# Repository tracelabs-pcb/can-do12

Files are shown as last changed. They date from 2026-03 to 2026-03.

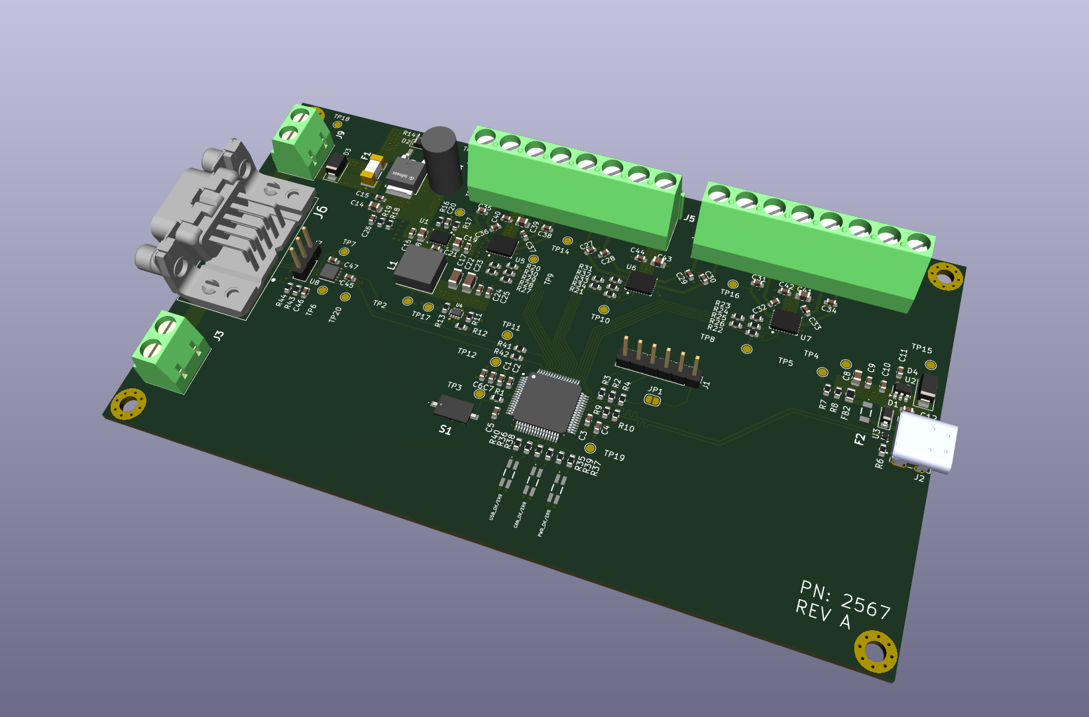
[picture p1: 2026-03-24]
screenshots/pcb_3d.png

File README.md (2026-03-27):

# CAN-DO12 — 24V Aktor-Modul (12x High-Side Digital Outputs)

**Status: PCB-Design abgeschlossen — unbestückt**  
**Tool:** KiCad | **Layer:** 4-Layer | **Hersteller-ready:** Ja

---

## Projektbeschreibung

Kompaktes 24V-Aktormodul zur Ansteuerung von 12 digitalen Lasten 
im Labor- und Prüfstandsbetrieb. Ansteuerung über CAN 2.0B, 
zusätzlich USB-C Service-Port für Parametrierung und Diagnose.
Entwickelt als Prototyp für Prüfstands- und Sondermaschinenbau.

**Besonderheiten:**
- 12x High-Side Ausgänge (24V / 1A je Kanal)
- CAN 2.0B (1 Mbit/s) + USB-C Full-Speed Device
- TVS + Verpolschutz am 24V Eingang
- ESD-Schutz an CAN und USB
- 4-Layer Layout, 140×80mm, Hutschienen-tauglich

---

## Hardware

| Komponente | Beschreibung |
|---|---|
| MCU | USB FS + CAN (STM32-Familie) |
| Ausgangstreiber | 12x High-Side, 24V |
| Schnittstellen | CAN 2.0B, USB-C, SWD |
| Versorgung | 18…30V DC, Buck → 3.3V |
| Schutz | TVS, Verpolschutz, ESD |
| Stackup | 4-Layer (Signal / GND / PWR / Signal) |
| Tool | KiCad |

---

## Anschlüsse

- USB-C (kurze Kante, mittig)
- DE-9 CAN-Stecker
- 2-pol Schraubklemme 24V Eingang
- 2x 8-pol Schraubklemme Ausgänge
- SWD Header (2.54mm)
- Jumper CAN-Terminierung 120Ω

---

## Ausschlüsse

Kein Serienprodukt — kein CE/EMV, keine Safety-Anwendung,
keine galvanische Trennung, keine Firmware.

---

## Dateien in diesem Repository

- `/kicad/` — KiCad Projektdateien
- `/screenshots/` — PCB- und Schematic-Ansichten

---

> Entwickelt von [Shawn Schneider](https://tracelabs-pcb.de)  
> — PCB-Design & Lötservice, Wolfsburg

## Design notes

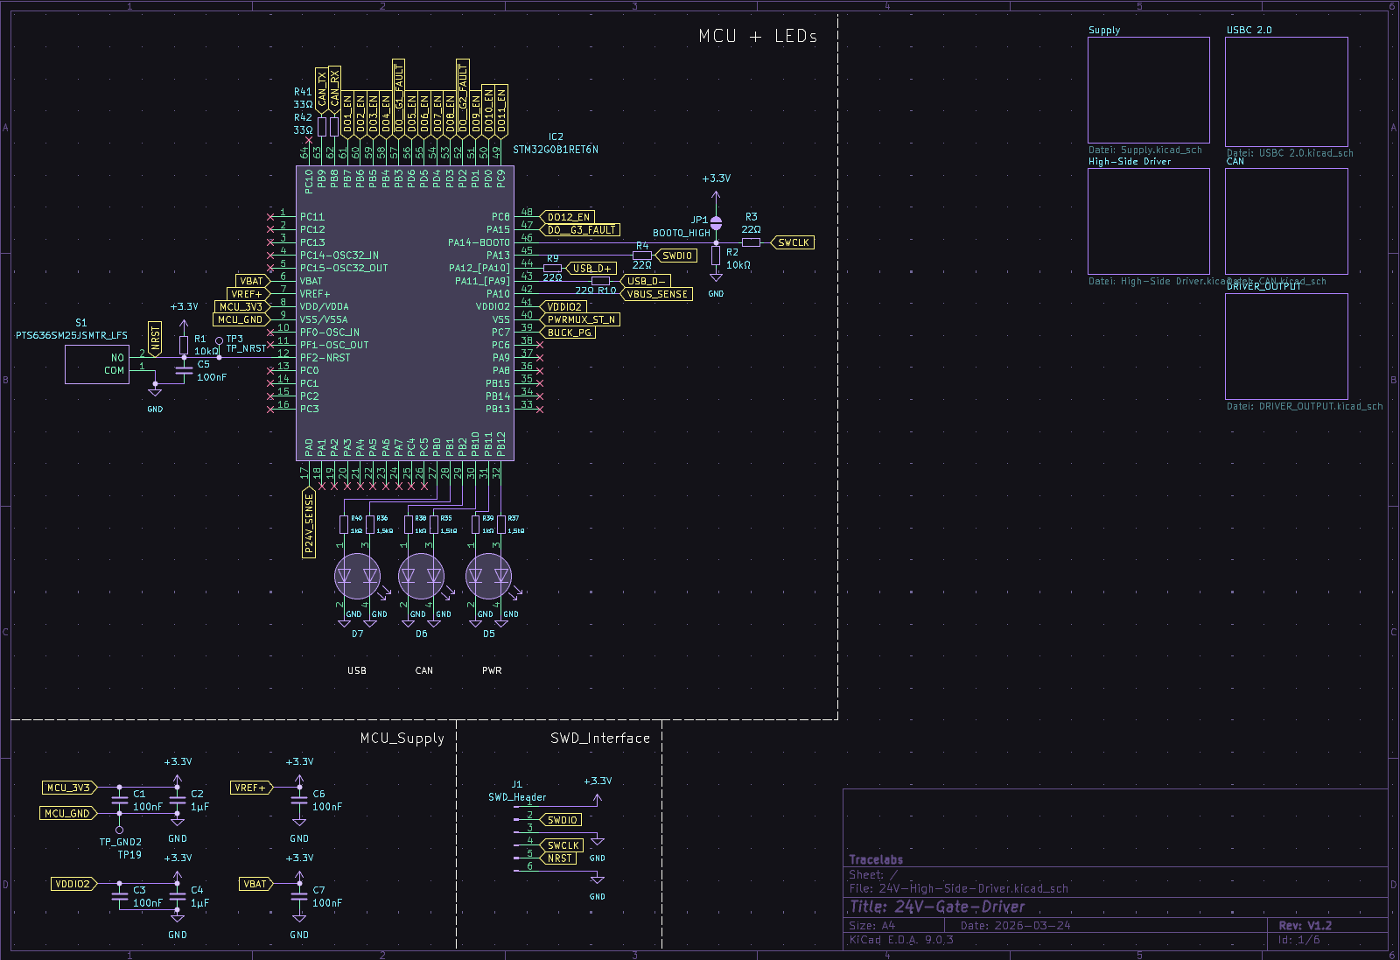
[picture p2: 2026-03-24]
screenshots/schematic_main.png

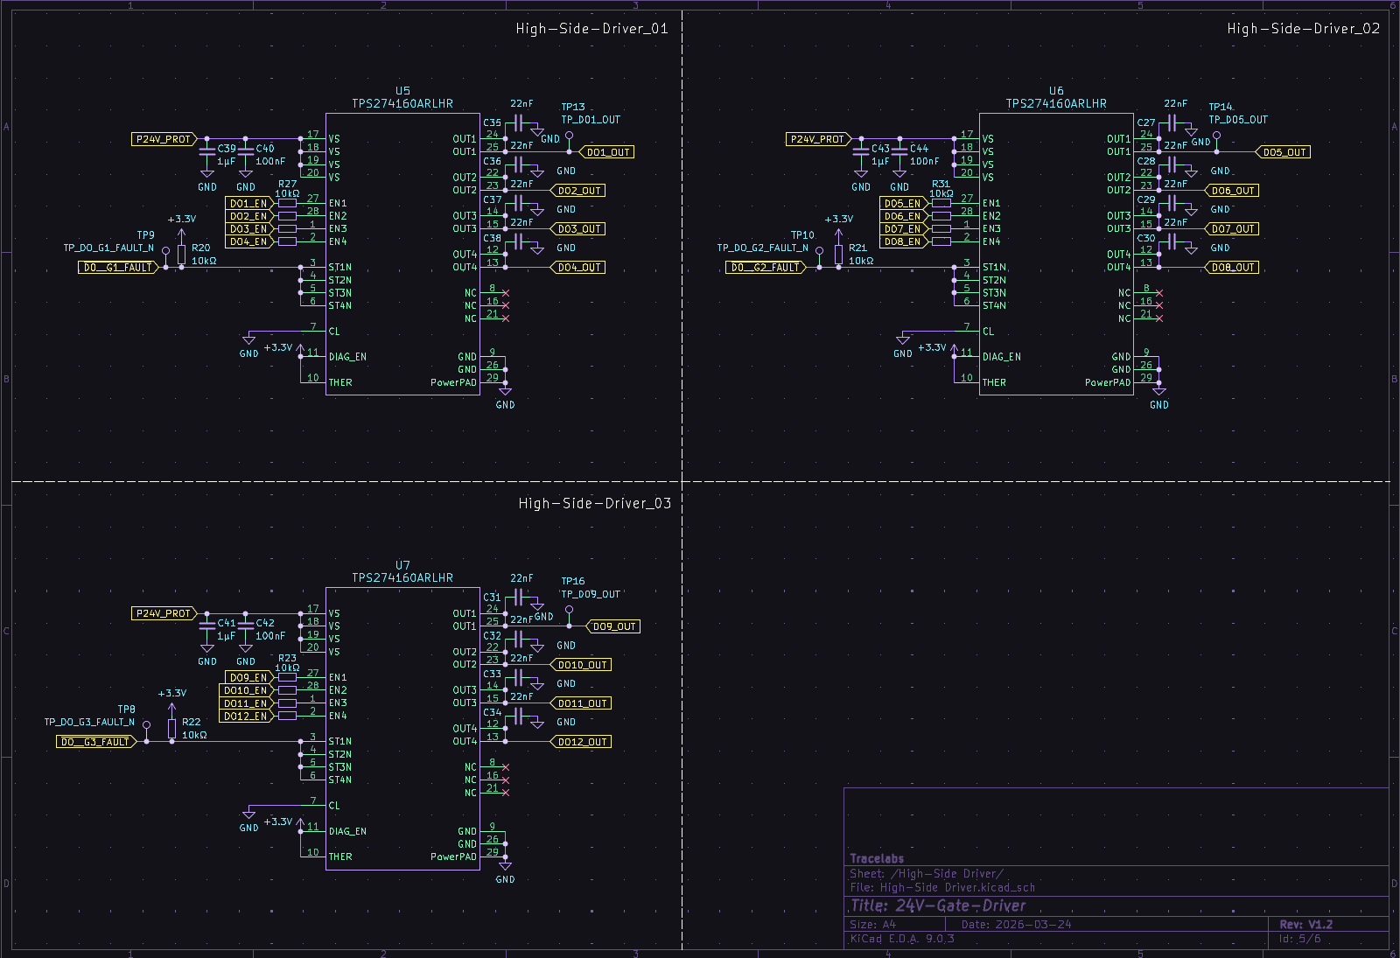
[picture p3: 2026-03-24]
screenshots/schematic_driver.png

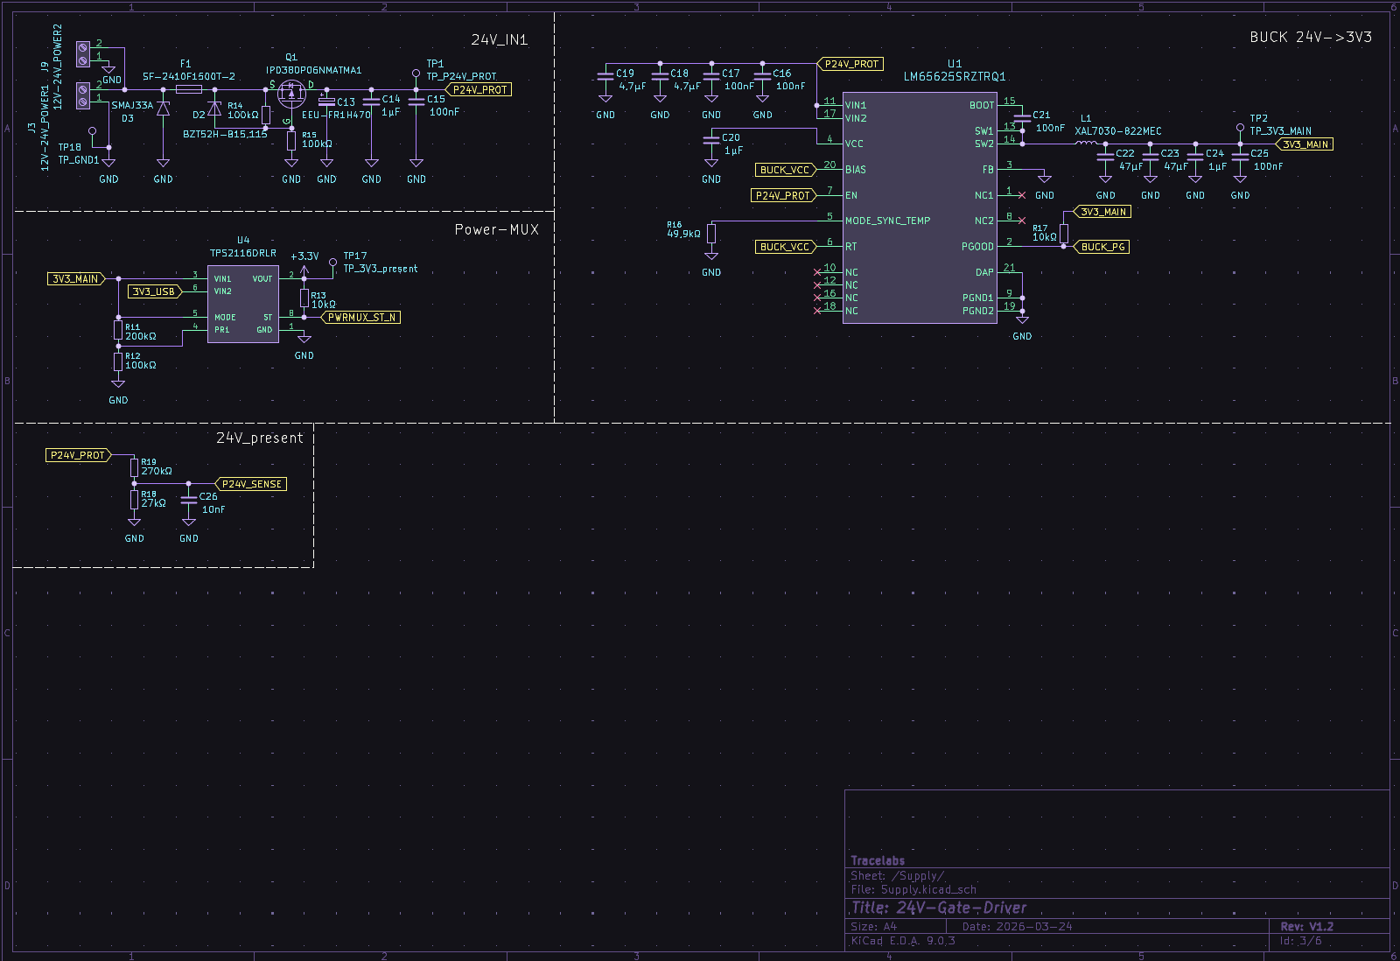
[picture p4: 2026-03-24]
screenshots/schematic_supply.png

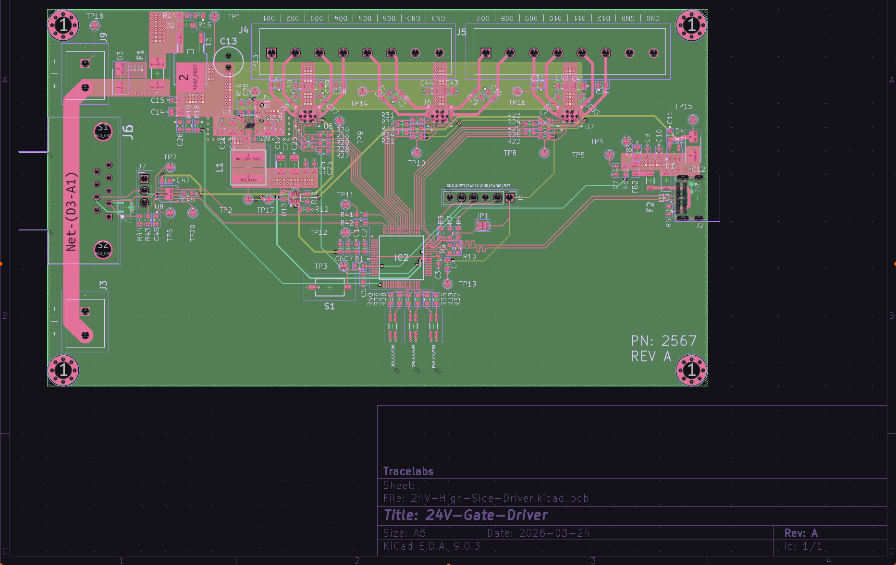
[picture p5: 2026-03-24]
screenshots/pcb_all_layers.png

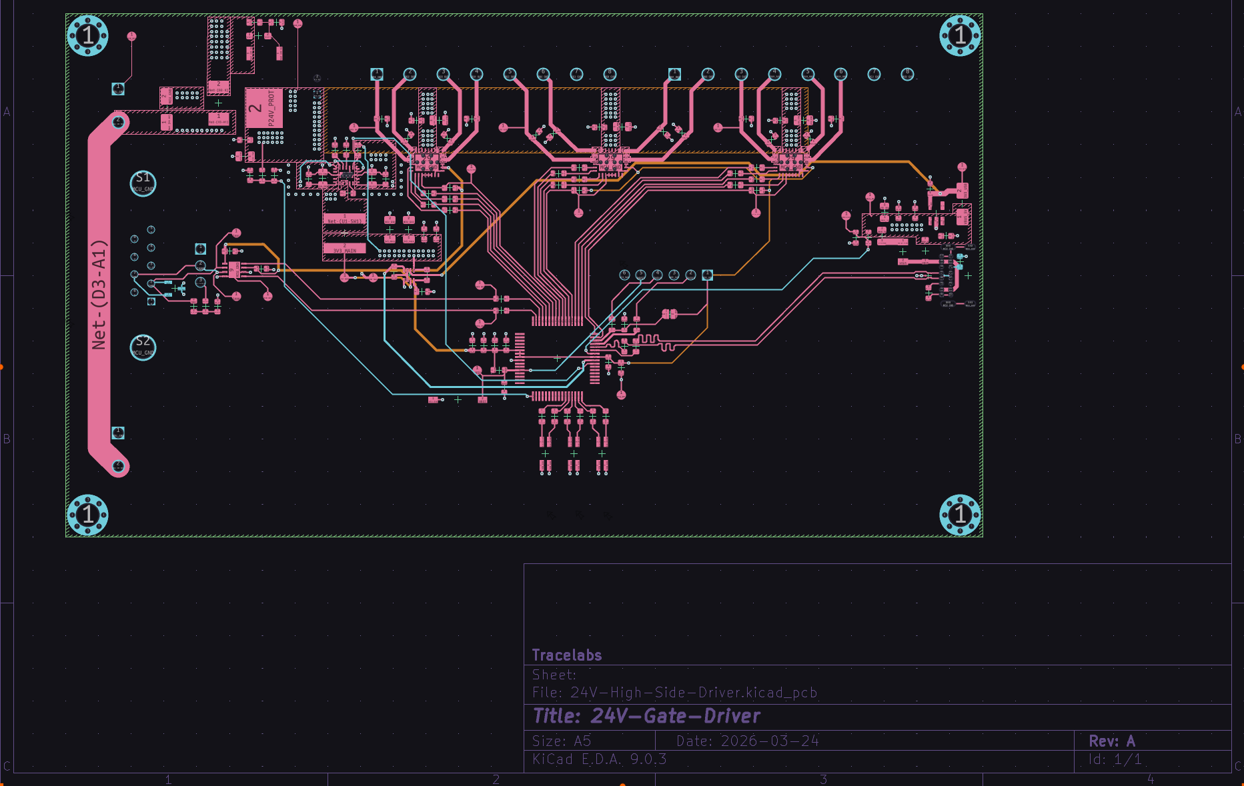
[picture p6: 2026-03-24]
screenshots/pcb_routing.png

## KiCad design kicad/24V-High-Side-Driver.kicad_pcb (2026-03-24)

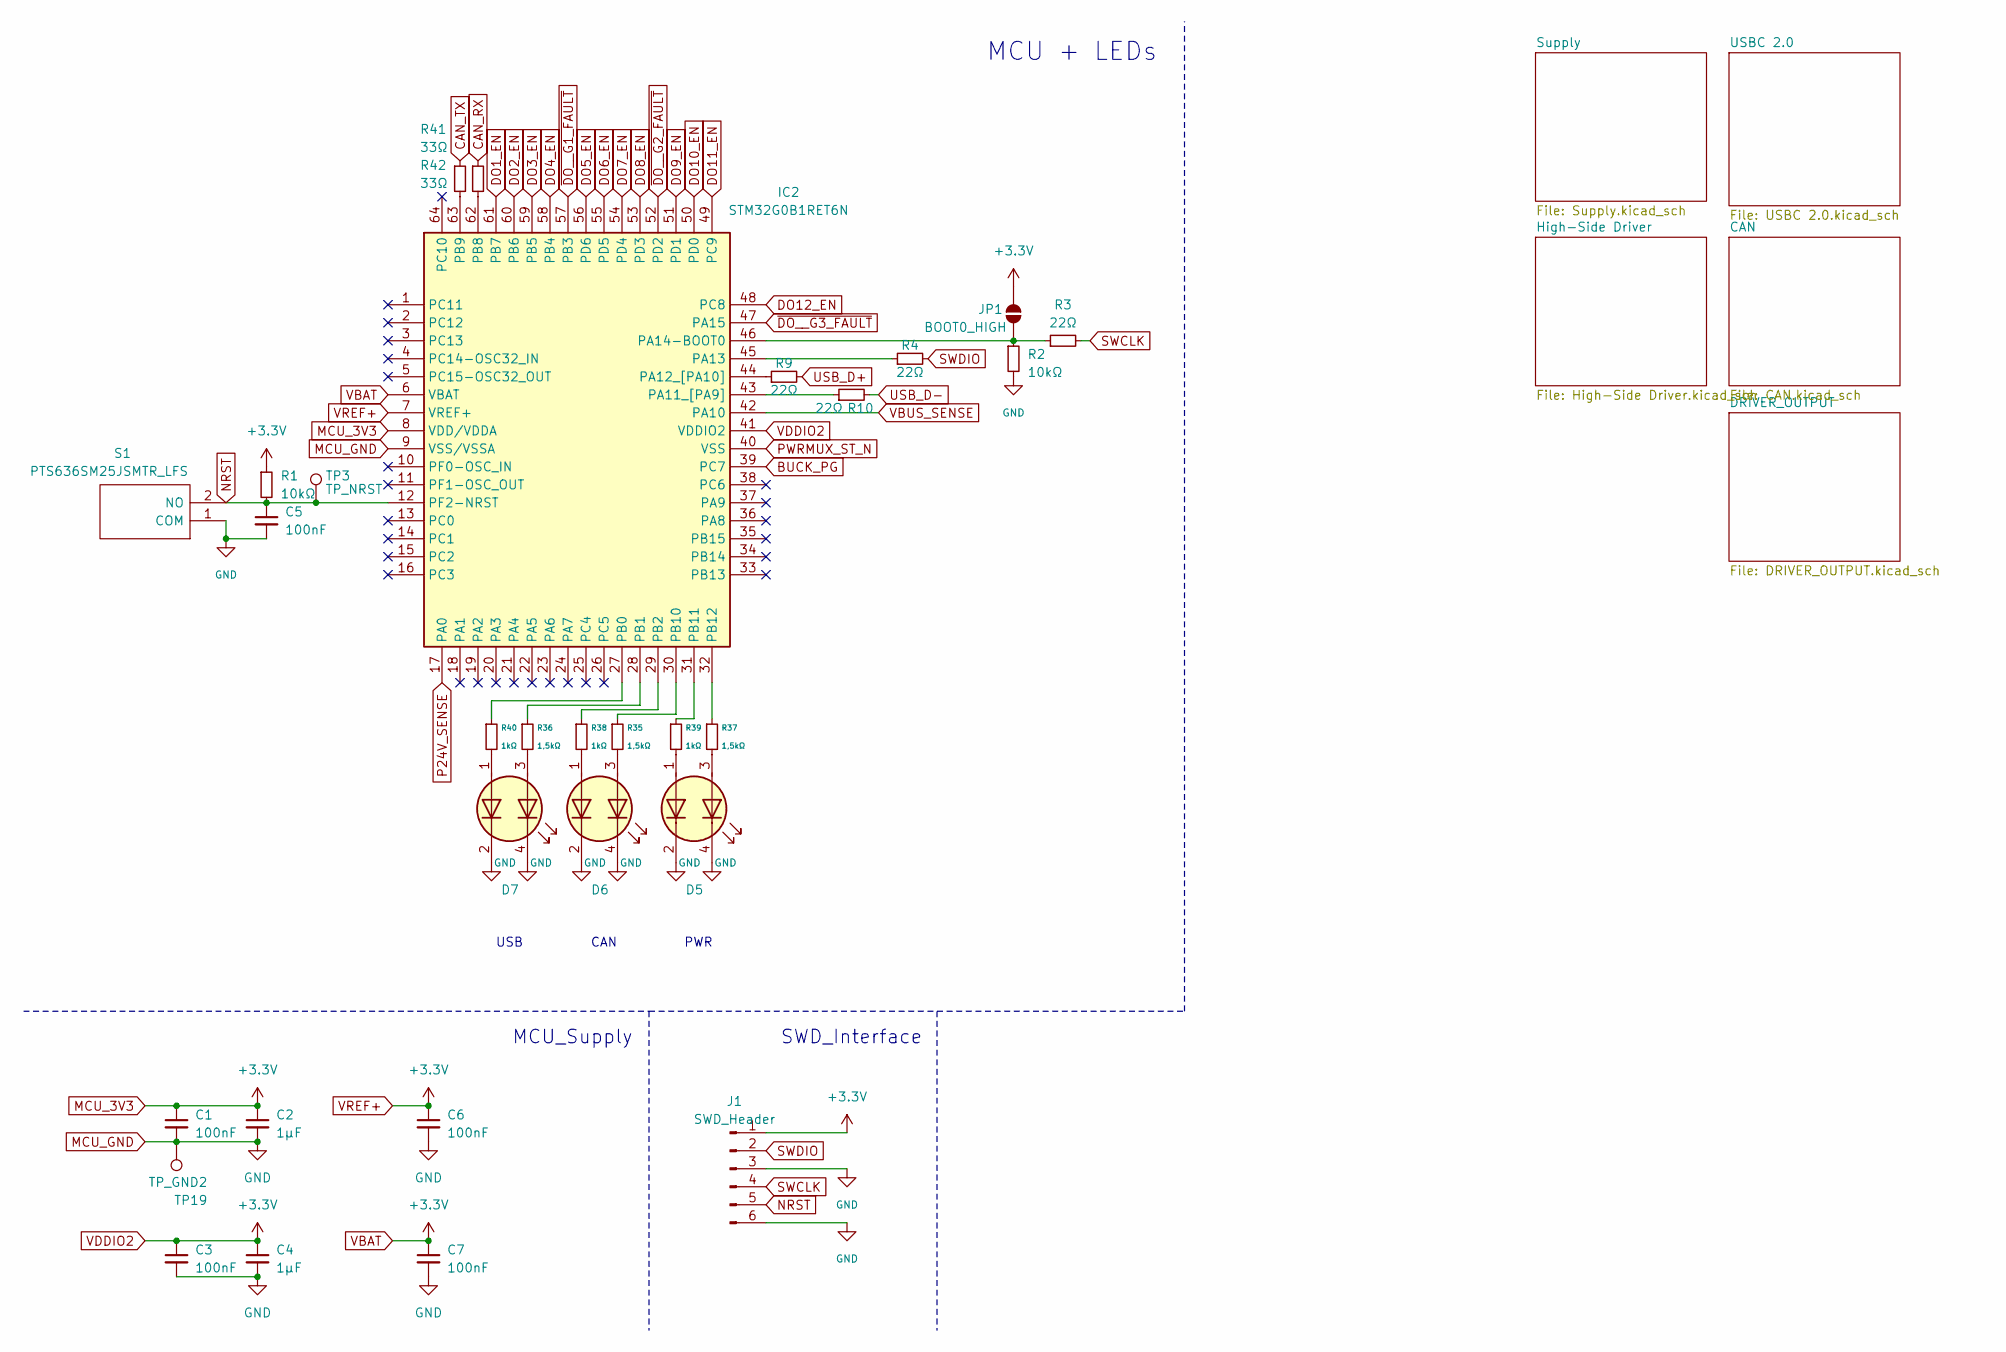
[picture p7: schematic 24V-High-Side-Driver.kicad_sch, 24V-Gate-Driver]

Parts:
C1, C3, C5, C6, C7: 100nF; C_0603_1608Metric
C2, C4: 1µF; C_0603_1608Metric
D5, D6, D7: APTBD3216SURKCGKC-01; APTBD3216SURKCGKC01
IC2: STM32G0B1RET6N; QFP50P1200X1200X160-64N; Mouser Part Number 511-STM32G0B1RET6N
J1: SWD_Header; PinHeader_1x06_P2.54mm_Vertical
JP1: BOOT0_HIGH; SolderJumper-2_P1.3mm_Open_RoundedPad1.0x1.5mm
R1, R2: 10kΩ; R_0603_1608Metric
R3, R4, R9, R10: 22Ω; R_0603_1608Metric
R35, R36, R37: 1,5kΩ; R_0603_1608Metric
R38, R39, R40: 1kΩ; R_0603_1608Metric
R41, R42: 33Ω; R_0603_1608Metric
S1: PTS636SM25JSMTR_LFS; PTS636SM25JSMTRLFS; Manufacturer_Part_Number PTS636SM25JSMTR LFS
TP3: TP_NRST; TestPoint_Pad_D1.5mm
TP19: TP_GND2; TestPoint_Pad_D1.5mm

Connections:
BUCK_PG: IC2.39 (PC7); also elsewhere on the board
CAN_RX: R41.1; also elsewhere on the board
CAN_TX: R42.1; also elsewhere on the board
DO1_EN: IC2.61 (PB7); also elsewhere on the board
DO2_EN: IC2.60 (PB6); also elsewhere on the board
DO3_EN: IC2.59 (PB5); also elsewhere on the board
DO4_EN: IC2.58 (PB4); also elsewhere on the board
DO5_EN: IC2.56 (PD6); also elsewhere on the board
DO6_EN: IC2.55 (PD5); also elsewhere on the board
DO7_EN: IC2.54 (PD4); also elsewhere on the board
DO8_EN: IC2.53 (PD3); also elsewhere on the board
DO9_EN: IC2.51 (PD1); also elsewhere on the board
DO10_EN: IC2.50 (PD0); also elsewhere on the board
DO11_EN: IC2.49 (PC9); also elsewhere on the board
DO12_EN: IC2.48 (PC8); also elsewhere on the board
MCU_3V3: C1.1, C2.1, C3.1, C4.1, C6.1, C7.1, IC2.6 (VBAT), IC2.7 (VREF+), IC2.8 (VDD/VDDA), IC2.41 (VDDIO2), J1.1, JP1.2 (B), R1.1; also elsewhere on the board
MCU_GND: C1.2, C2.2, C3.2, C4.2, C5.2, C6.2, C7.2, D5.2 (K1), D5.4 (K2), D6.2 (K1), D6.4 (K2), D7.2 (K1), D7.4 (K2), IC2.9 (VSS/VSSA), J1.3, J1.6, R2.2, S1.1 (COM), TP19.1; also elsewhere on the board
NRST: C5.1, IC2.12 (PF2-NRST), J1.5, R1.2, S1.2 (NO), TP3.1
unnamed: D5.1 (A1), R39.2
unnamed: D5.3 (A2), R37.2
unnamed: D6.1 (A1), R38.2
unnamed: D6.3 (A2), R35.2
unnamed: D7.1 (A1), R40.2
unnamed: D7.3 (A2), R36.2
unnamed: IC2.43 (PA11_[PA9]), R10.1
unnamed: IC2.44 (PA12_[PA10]), R9.1
unnamed: IC2.45 (PA13), R4.1
unnamed: IC2.46 (PA14-BOOT0), JP1.1 (A), R2.1, R3.1
unnamed: IC2.27 (PB0), R40.1
unnamed: IC2.28 (PB1), R36.1
unnamed: IC2.29 (PB2), R38.1
unnamed: IC2.62 (PB8), R41.2
unnamed: IC2.63 (PB9), R42.2
unnamed: IC2.30 (PB10), R35.1
unnamed: IC2.31 (PB11), R39.1
unnamed: IC2.32 (PB12), R37.1
P24V_SENSE: IC2.17 (PA0); also elsewhere on the board
PWRMUX_ST_N: IC2.40 (VSS); also elsewhere on the board
SWCLK: J1.4, R3.2
SWDIO: J1.2, R4.2
USB_D+: R9.2; also elsewhere on the board
USB_D-: R10.2; also elsewhere on the board
VBUS_SENSE: IC2.42 (PA10); also elsewhere on the board
~DO__G1_FAULT: IC2.57 (PB3); also elsewhere on the board
~DO__G2_FAULT: IC2.52 (PD2); also elsewhere on the board
~DO__G3_FAULT: IC2.47 (PA15); also elsewhere on the board

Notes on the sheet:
SWD_Interface
MCU_Supply
PWR
CAN
USB
MCU + LEDs

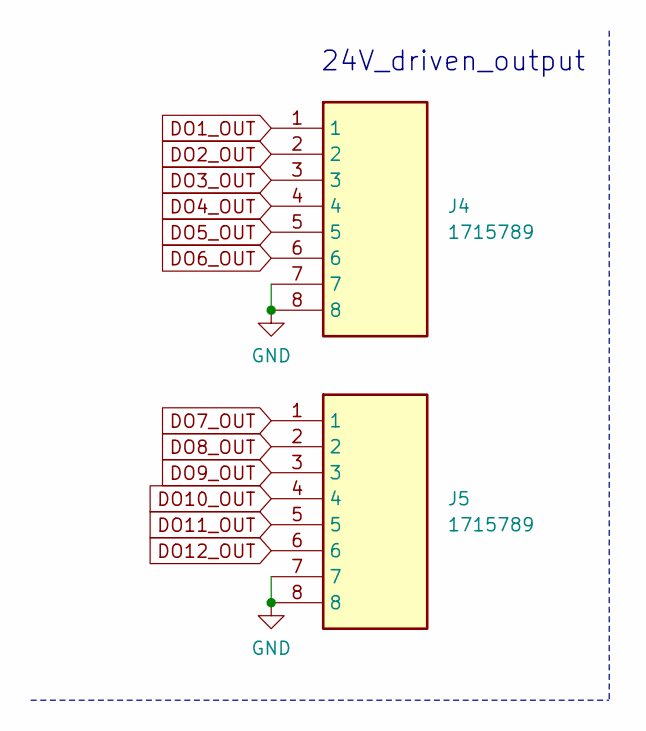
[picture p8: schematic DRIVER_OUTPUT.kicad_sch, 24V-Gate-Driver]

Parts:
J4, J5: 1715789; Mouser Part Number 651-1715789

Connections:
DO1_OUT: J4.1; also elsewhere on the board
DO2_OUT: J4.2; also elsewhere on the board
DO3_OUT: J4.3; also elsewhere on the board
DO4_OUT: J4.4; also elsewhere on the board
DO5_OUT: J4.5; also elsewhere on the board
DO6_OUT: J4.6; also elsewhere on the board
DO7_OUT: J5.1; also elsewhere on the board
DO8_OUT: J5.2; also elsewhere on the board
DO9_OUT: J5.3; also elsewhere on the board
DO10_OUT: J5.4; also elsewhere on the board
DO11_OUT: J5.5; also elsewhere on the board
DO12_OUT: J5.6; also elsewhere on the board
MCU_GND: J4.7, J4.8, J5.7, J5.8; also elsewhere on the board

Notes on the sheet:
24V_driven_output

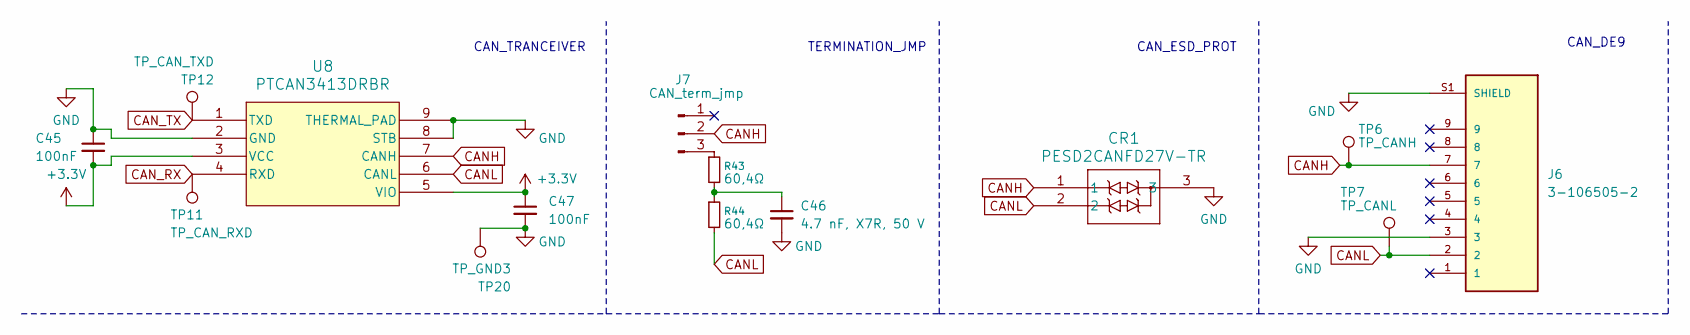
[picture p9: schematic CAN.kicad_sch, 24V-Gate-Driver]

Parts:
C45, C47: 100nF; C_0603_1608Metric
C46: 4.7 nF, X7R, 50 V; C_0603_1608Metric
CR1: PESD2CANFD27V-TR; SOT23_PESD2_NEX
J6: 3-106505-2; TE_3-106505-2; PART_REV M; DigiKey_Part_Number A105026-ND
J7: CAN_term_jmp; PinHeader_1x03_P2.54mm_Vertical
R43, R44: 60,4Ω; R_0603_1608Metric
TP6: TP_CANH; TestPoint_Pad_D1.5mm
TP7: TP_CANL; TestPoint_Pad_D1.5mm
TP11: TP_CAN_RXD; TestPoint_Pad_D1.5mm
TP12: TP_CAN_TXD; TestPoint_Pad_D1.5mm
TP20: TP_GND3; TestPoint_Pad_D1.5mm
U8: PTCAN3413DRBR; VSON8-DRB_TEX

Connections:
CANH: CR1.1, J6.7, J7.2, TP6.1, U8.7 (CANH)
CANL: CR1.2, J6.2, R44.2, TP7.1, U8.6 (CANL)
CAN_RX: TP11.1, U8.4 (RXD); also elsewhere on the board
CAN_TX: TP12.1, U8.1 (TXD); also elsewhere on the board
MCU_3V3: C45.2, C47.1, U8.3 (VCC), U8.5 (VIO); also elsewhere on the board
MCU_GND: C45.1, C46.2, C47.2, CR1.3, J6.3, J6.S1 (SHIELD), J6.S2 (SHIELD), TP20.1, U8.2 (GND), U8.8 (STB), U8.9 (THERMAL_PAD); also elsewhere on the board
unnamed: C46.1, R43.2, R44.1
unnamed: J7.3, R43.1

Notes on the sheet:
TERMINATION_JMP
CAN_ESD_PROT
CAN_DE9
CAN_TRANCEIVER

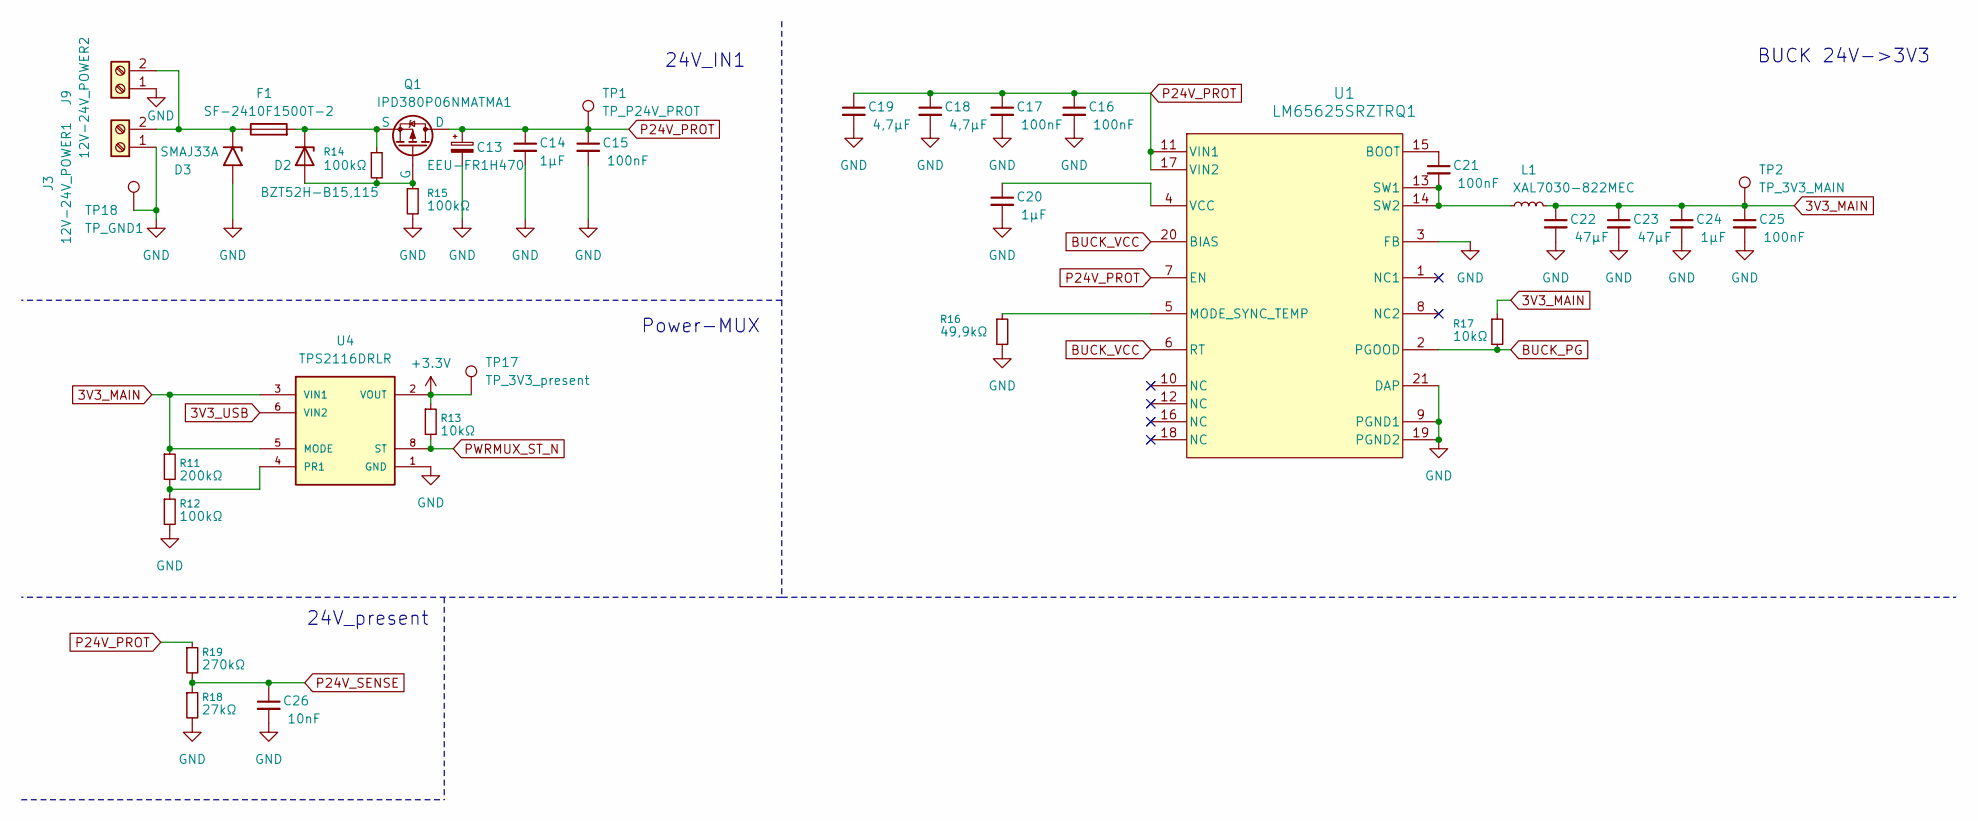
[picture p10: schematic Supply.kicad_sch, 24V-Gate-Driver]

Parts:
C13: EEU-FR1H470; CAPPRD250W55D630H1270
C14: 1µF; C_0805_2012Metric
C15, C16, C17, C21, C25: 100nF; C_0603_1608Metric
C18, C19: 4,7µF; C_0805_2012Metric
C20, C24: 1µF; C_0603_1608Metric
C22, C23: 47µF; C_1206_3216Metric
C26: 10nF; C_0603_1608Metric
D2: BZT52H-B15,115; D_SOD-123F
D3: SMAJ33A; D_SMA
F1: SF-2410F1500T-2; SF2410F1500T2
J3: 12V-24V_POWER1; 1729128
J9: 12V-24V_POWER2; 1729128
L1: XAL7030-822MEC; XAL7030822MEC
Q1: IPD380P06NMATMA1; PG-TO252-3-313_INF
R11: 200kΩ; R_0603_1608Metric
R12, R14, R15: 100kΩ; R_0603_1608Metric
R13, R17: 10kΩ; R_0603_1608Metric
R16: 49,9kΩ; R_0603_1608Metric
R18: 27kΩ; R_0603_1608Metric
R19: 270kΩ; R_0603_1608Metric
TP1: TP_P24V_PROT; TestPoint_Pad_D1.5mm
TP2: TP_3V3_MAIN; TestPoint_Pad_D1.5mm
TP17: TP_3V3_present; TestPoint_Pad_D1.5mm
TP18: TP_GND1; TestPoint_Pad_D1.5mm
U1: LM65625SRZTRQ1; RZT0020A-MFG
U4: TPS2116DRLR; SOTFL50P160X60-8N; PARTREV A; DigiKey_Part_Number 296-TPS2116DRLRCT-ND

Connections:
3V3_MAIN: C22.1, C23.1, C24.1, C25.1, L1.2, R11.1, R17.1, TP2.1, U4.3 (VIN1), U4.5 (MODE)
3V3_USB: U4.6 (VIN2); also elsewhere on the board
BUCK_PG: R17.2, U1.2 (PGOOD); also elsewhere on the board
BUCK_VCC: U1.6 (RT), U1.20 (BIAS)
MCU_3V3: R13.1, TP17.1, U4.2 (VOUT), U4.7 (VOUT); also elsewhere on the board
MCU_GND: C13.2, C14.2, C15.2, C16.2, C17.2, C18.2, C19.2, C20.2, C22.2, C23.2, C24.2, C25.2, C26.2, D3.2 (A2), J3.1, J9.1, R12.2, R15.2, R16.2, R18.2, TP18.1, U1.3 (FB), U1.9 (PGND1), U1.19 (PGND2), U1.21 (DAP), U1.22 (DAP), U1.23 (DAP), U1.24 (DAP), U1.25 (DAP), U1.26 (DAP), U1.27 (DAP), U4.1 (GND); also elsewhere on the board
unnamed: D2.2 (A), Q1.1 (G), R14.2, R15.1
unnamed: D2.1 (K), F1.2, Q1.3 (S), R14.1
unnamed: D3.1 (A1), F1.1, J3.2, J9.2
unnamed: C21.1, U1.15 (BOOT)
unnamed: R16.1, U1.5 (MODE_SYNC_TEMP)
unnamed: C21.2, L1.1, U1.13 (SW1), U1.14 (SW2)
unnamed: C20.1, U1.4 (VCC)
unnamed: R11.2, R12.1, U4.4 (PR1)
P24V_PROT: C13.1, C14.1, C15.1, C16.1, C17.1, C18.1, C19.1, Q1.2 (D), R19.1, TP1.1, U1.7 (EN), U1.11 (VIN1), U1.17 (VIN2); also elsewhere on the board
P24V_SENSE: C26.1, R18.1, R19.2; also elsewhere on the board
PWRMUX_ST_N: R13.2, U4.8 (ST); also elsewhere on the board

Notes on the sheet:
BUCK 24V->3V3
24V_IN1
Power-MUX
24V_present

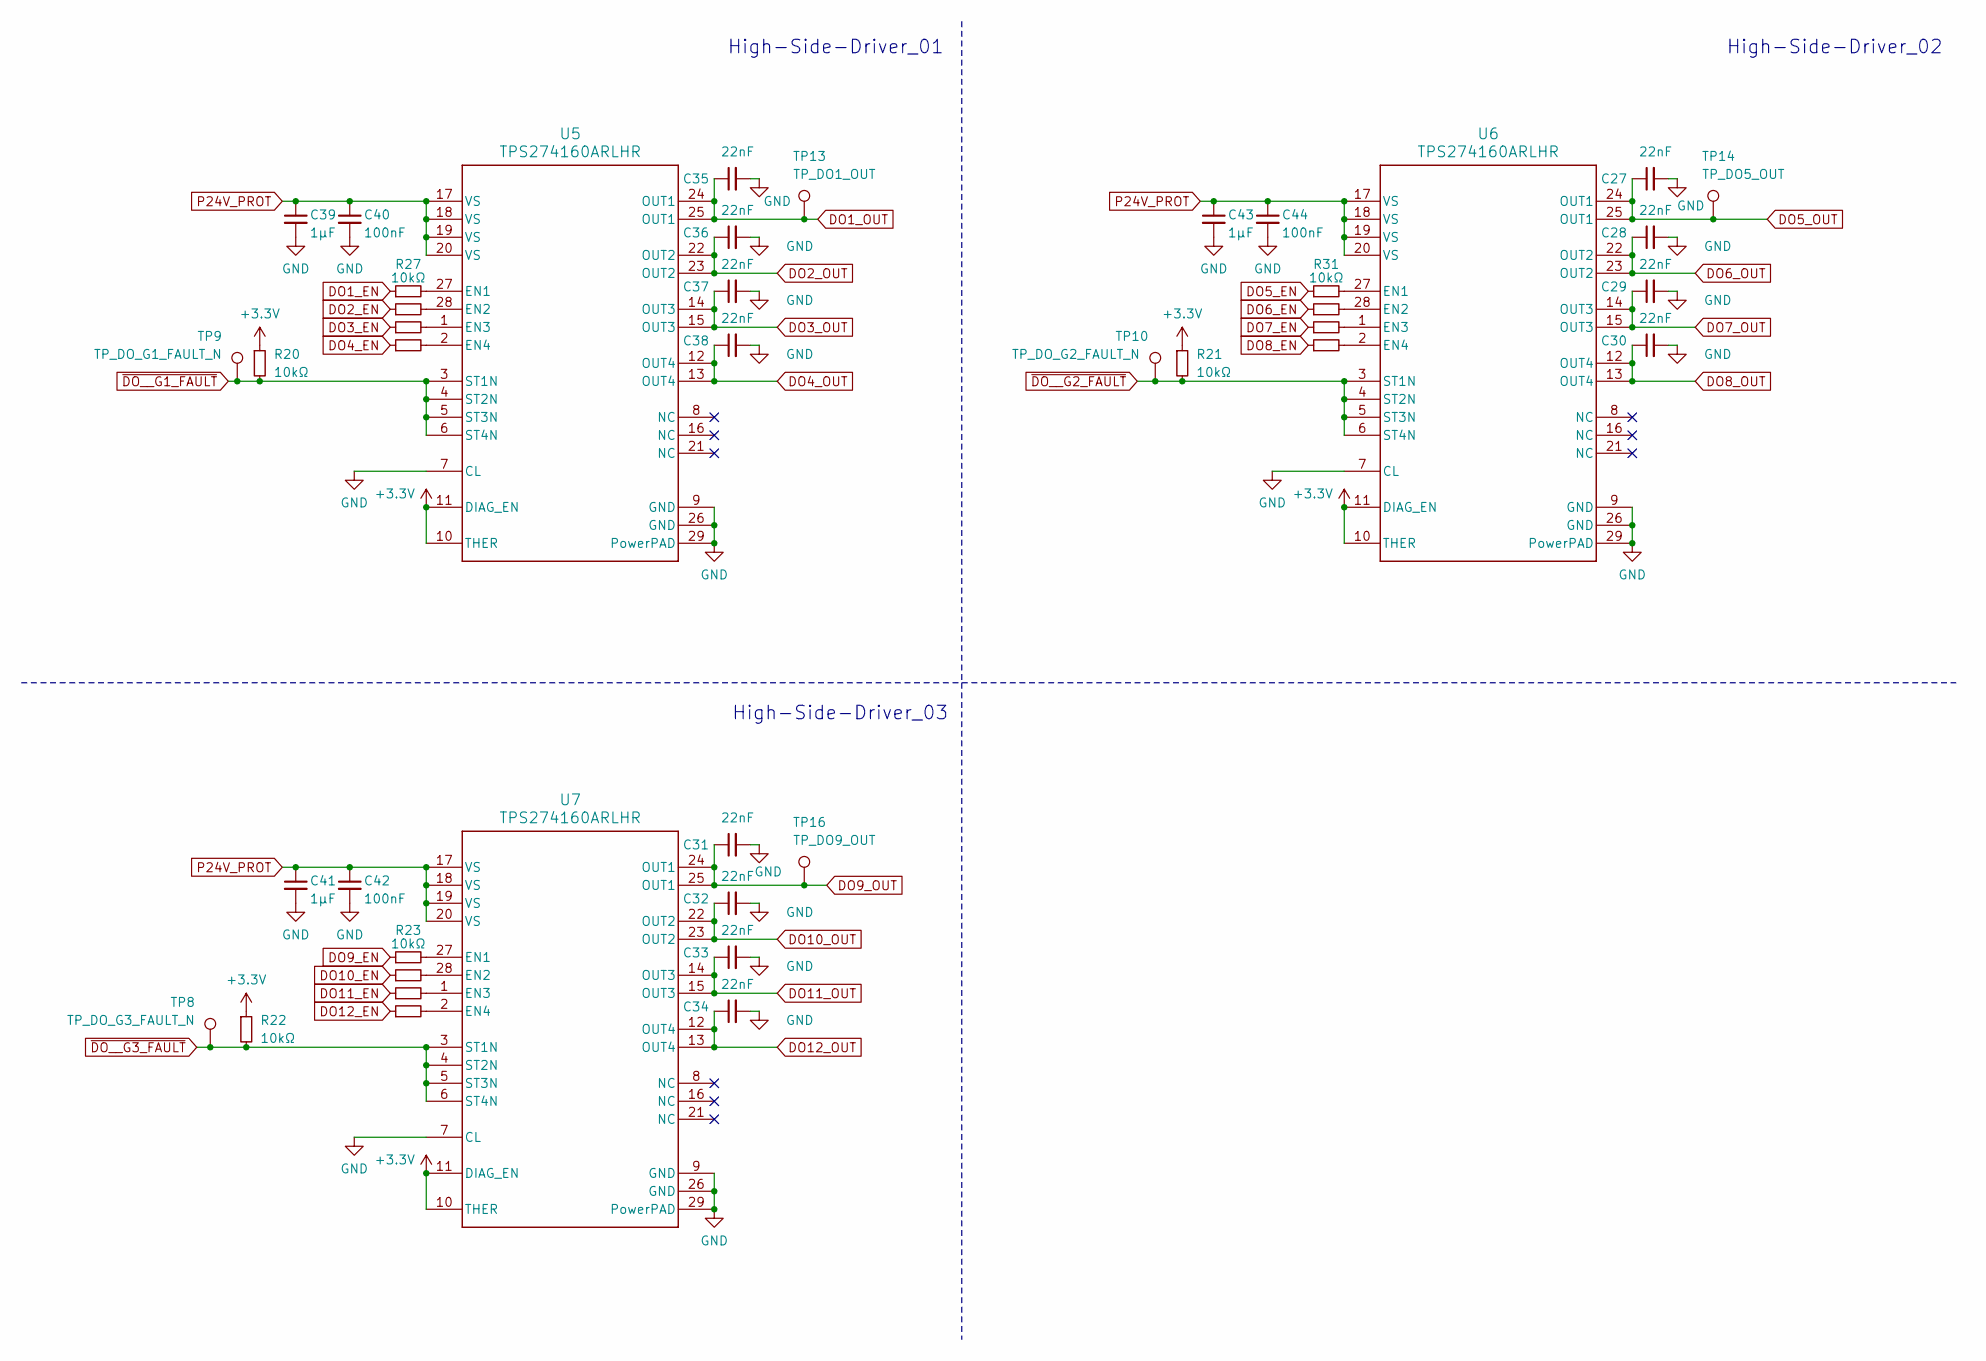
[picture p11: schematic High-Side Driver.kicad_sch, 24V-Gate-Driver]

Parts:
C27, C28, C29, C30, C31, C32, C33, C34, C35, C36, C37, C38: 22nF; C_0603_1608Metric
C39, C41, C43: 1µF; C_0805_2012Metric
C40, C42, C44: 100nF; C_0603_1608Metric
R20, R21, R22, R23, R24, R25, R26, R27, R28, R29, R30, R31, R32, R33, R34: 10kΩ; R_0603_1608Metric
TP8: TP_DO_G3_FAULT_N; TestPoint_Pad_D1.5mm
TP9: TP_DO_G1_FAULT_N; TestPoint_Pad_D1.5mm
TP10: TP_DO_G2_FAULT_N; TestPoint_Pad_D1.5mm
TP13: TP_DO1_OUT; TestPoint_Pad_D1.5mm
TP14: TP_DO5_OUT; TestPoint_Pad_D1.5mm
TP16: TP_DO9_OUT; TestPoint_Pad_D1.5mm
U5, U6, U7: TPS274160ARLHR; RLH0028A-MFG

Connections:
DO1_EN: R27.1; also elsewhere on the board
DO1_OUT: C35.1, TP13.1, U5.24 (OUT1), U5.25 (OUT1); also elsewhere on the board
DO2_EN: R28.1; also elsewhere on the board
DO2_OUT: C36.1, U5.22 (OUT2), U5.23 (OUT2); also elsewhere on the board
DO3_EN: R29.1; also elsewhere on the board
DO3_OUT: C37.1, U5.14 (OUT3), U5.15 (OUT3); also elsewhere on the board
DO4_EN: R30.1; also elsewhere on the board
DO4_OUT: C38.1, U5.12 (OUT4), U5.13 (OUT4); also elsewhere on the board
DO5_EN: R31.1; also elsewhere on the board
DO5_OUT: C27.1, TP14.1, U6.24 (OUT1), U6.25 (OUT1); also elsewhere on the board
DO6_EN: R32.1; also elsewhere on the board
DO6_OUT: C28.1, U6.22 (OUT2), U6.23 (OUT2); also elsewhere on the board
DO7_EN: R33.1; also elsewhere on the board
DO7_OUT: C29.1, U6.14 (OUT3), U6.15 (OUT3); also elsewhere on the board
DO8_EN: R34.1; also elsewhere on the board
DO8_OUT: C30.1, U6.12 (OUT4), U6.13 (OUT4); also elsewhere on the board
DO9_EN: R23.1; also elsewhere on the board
DO9_OUT: C31.1, TP16.1, U7.24 (OUT1), U7.25 (OUT1); also elsewhere on the board
DO10_EN: R24.1; also elsewhere on the board
DO10_OUT: C32.1, U7.22 (OUT2), U7.23 (OUT2); also elsewhere on the board
DO11_EN: R25.1; also elsewhere on the board
DO11_OUT: C33.1, U7.14 (OUT3), U7.15 (OUT3); also elsewhere on the board
DO12_EN: R26.1; also elsewhere on the board
DO12_OUT: C34.1, U7.12 (OUT4), U7.13 (OUT4); also elsewhere on the board
MCU_3V3: R20.1, R21.1, R22.1, U5.10 (THER), U5.11 (DIAG_EN), U6.10 (THER), U6.11 (DIAG_EN), U7.10 (THER), U7.11 (DIAG_EN); also elsewhere on the board
MCU_GND: C27.2, C28.2, C29.2, C30.2, C31.2, C32.2, C33.2, C34.2, C35.2, C36.2, C37.2, C38.2, C39.2, C40.2, C41.2, C42.2, C43.2, C44.2, U5.7 (CL), U5.9 (GND), U5.26 (GND), U5.29 (PowerPAD), U5.30 (GND), U5.31 (GND), U5.32 (GND), U5.33 (GND), U5.34 (GND), U5.35 (GND), U5.36 (GND), U5.37 (GND), U6.7 (CL), U6.9 (GND), U6.26 (GND), U6.29 (PowerPAD), U6.30 (GND), U6.31 (GND), U6.32 (GND), U6.33 (GND), U6.34 (GND), U6.35 (GND), U6.36 (GND), U6.37 (GND), U7.7 (CL), U7.9 (GND), U7.26 (GND), U7.29 (PowerPAD), U7.30 (GND), U7.31 (GND), U7.32 (GND), U7.33 (GND), U7.34 (GND), U7.35 (GND), U7.36 (GND), U7.37 (GND); also elsewhere on the board
unnamed: R27.2, U5.27 (EN1)
unnamed: R28.2, U5.28 (EN2)
unnamed: R29.2, U5.1 (EN3)
unnamed: R30.2, U5.2 (EN4)
unnamed: R31.2, U6.27 (EN1)
unnamed: R32.2, U6.28 (EN2)
unnamed: R33.2, U6.1 (EN3)
unnamed: R34.2, U6.2 (EN4)
unnamed: R23.2, U7.27 (EN1)
unnamed: R24.2, U7.28 (EN2)
unnamed: R25.2, U7.1 (EN3)
unnamed: R26.2, U7.2 (EN4)
P24V_PROT: C39.1, C40.1, C41.1, C42.1, C43.1, C44.1, U5.17 (VS), U5.18 (VS), U5.19 (VS), U5.20 (VS), U6.17 (VS), U6.18 (VS), U6.19 (VS), U6.20 (VS), U7.17 (VS), U7.18 (VS), U7.19 (VS), U7.20 (VS); also elsewhere on the board
~DO__G1_FAULT: R20.2, TP9.1, U5.3 (ST1N), U5.4 (ST2N), U5.5 (ST3N), U5.6 (ST4N); also elsewhere on the board
~DO__G2_FAULT: R21.2, TP10.1, U6.3 (ST1N), U6.4 (ST2N), U6.5 (ST3N), U6.6 (ST4N); also elsewhere on the board
~DO__G3_FAULT: R22.2, TP8.1, U7.3 (ST1N), U7.4 (ST2N), U7.5 (ST3N), U7.6 (ST4N); also elsewhere on the board

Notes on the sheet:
High-Side-Driver_03
High-Side-Driver_02
High-Side-Driver_01

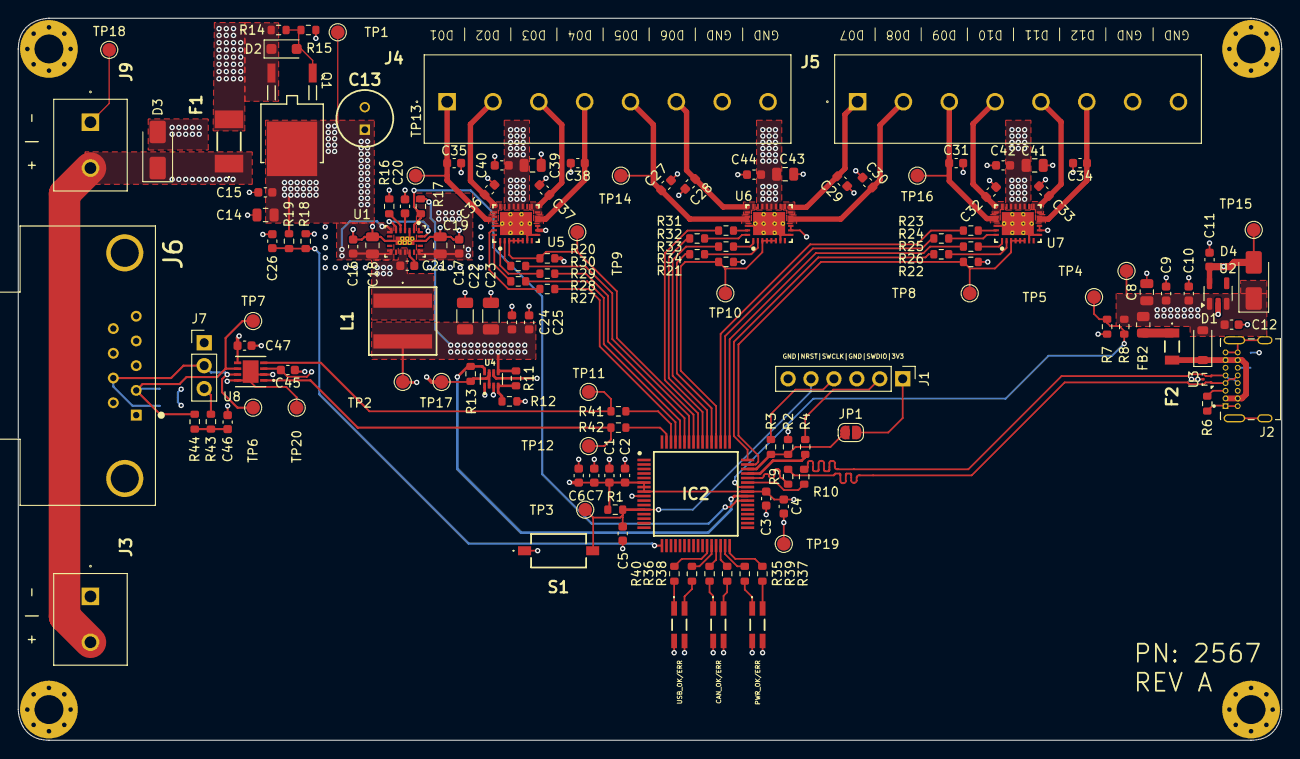
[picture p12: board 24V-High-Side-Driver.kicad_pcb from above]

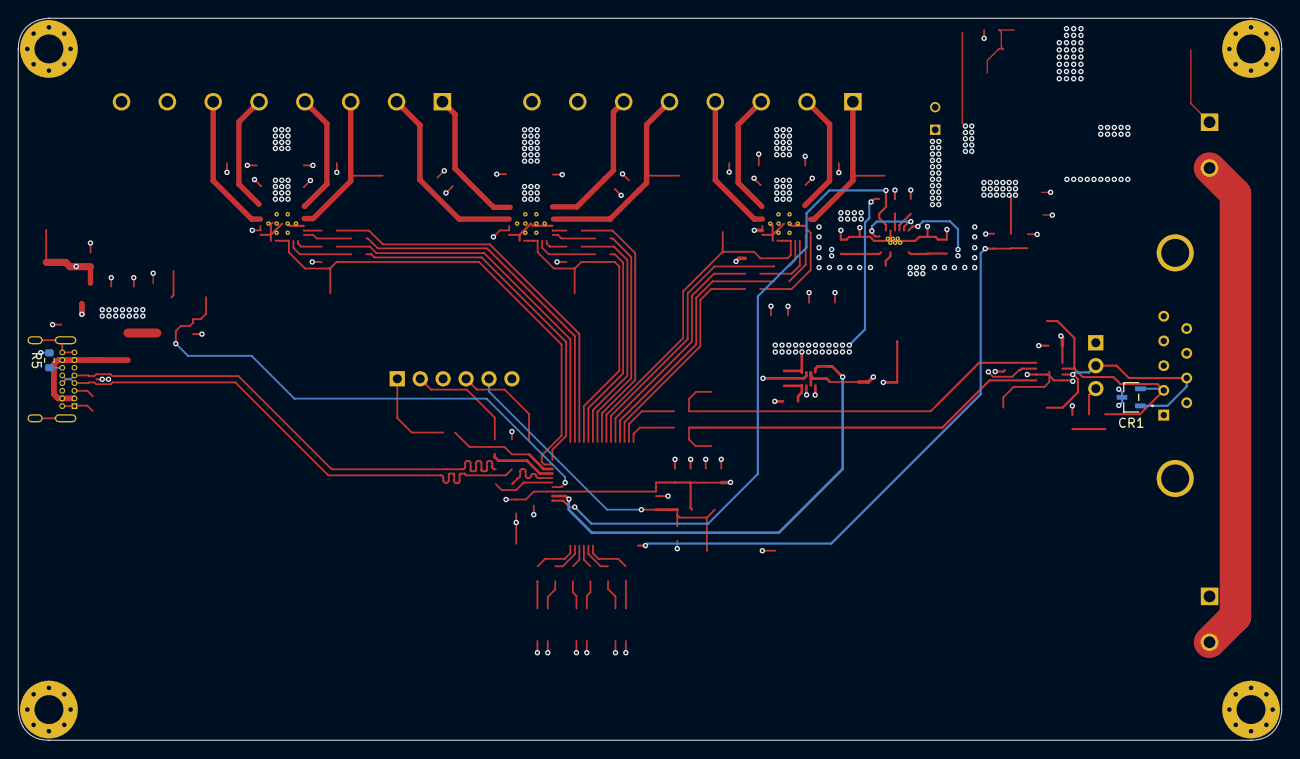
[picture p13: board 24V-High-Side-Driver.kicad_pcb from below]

Board: 4 copper layers, 140.0 x 80.0 mm, 143 parts (2 on the bottom side), 91 nets.

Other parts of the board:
C8: 10µF; C_0805_2012Metric
C9, C11, C12: 1µF; C_0603_1608Metric
C10: 100nF; C_0603_1608Metric
D1: Littelfuse SMF5.0A; D_SOD-123
D4: SS14; D_SMA
F2: MF-MSMF050/40X-2; MFNSMF07513X2
FB2: BLM21PG121SN1D; R_0805_2012Metric
J2: UJ20-C-H-G-SMT-TR; CUI_UJ20-C-H-G-SMT-TR
R5, R6: 5,1kΩ; R_0603_1608Metric
R7: 120kΩ; R_0603_1608Metric
R8: 100kΩ; R_0603_1608Metric
TP4: TP_USB_VBUS; TestPoint_Pad_D1.5mm
TP5: TP_VBUS_SENSE; TestPoint_Pad_D1.5mm
TP15: TP_3V3_USB; TestPoint_Pad_D1.5mm
U2: TLV75533PDBV; SOT-23-5
U3: TPD2EUSB30; Texas_DRT-3

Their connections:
3V3_USB: C11.1, D4.2 (A), TP15.1, U2.5 (OUT); also elsewhere on the board
MCU_GND: C8.2, C9.2, C10.2, C11.2, C12.2, J2.A1 (GND), J2.A12 (GND), J2.B1 (GND), J2.B12 (GND), J2.SH1 (SHIELD), J2.SH2 (SHIELD), J2.SH3 (SHIELD), J2.SH4 (SHIELD), R5.2, R6.2, R7.1, U2.2 (GND), U3.3 (GND); also elsewhere on the board
unnamed: F2.1, FB2.1
unnamed: J2.A5 (CC1), R6.1
unnamed: J2.B5 (CC2), R5.1
USB_D+: J2.A6 (DP1), J2.B6 (DP2), U3.1 (D+); also elsewhere on the board
USB_D-: J2.A7 (DN1), J2.B7 (DN2), U3.2 (D-); also elsewhere on the board
VBUS: D1.1 (A1), F2.2, J2.A4 (VBUS), J2.A9 (VBUS), J2.B4 (VBUS), J2.B9 (VBUS)
VBUS_5V: C8.1, C9.1, C10.1, C12.1, D1.2 (A2), D4.1 (K), FB2.2, R8.2, TP4.1, U2.1 (IN), U2.3 (EN)
VBUS_SENSE: R7.2, R8.1, TP5.1; also elsewhere on the board

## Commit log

2026-03-24 Add kicad folder
2026-03-24 Add KiCad project files
    [24V-High-Side-Driver.kicad_pcb, 24V-High-Side-Driver.kicad_sch, CAN.kicad_sch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]
